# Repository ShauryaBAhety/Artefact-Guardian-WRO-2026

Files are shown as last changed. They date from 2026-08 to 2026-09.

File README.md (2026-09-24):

# Artefact Guardian 🤖

### A robotic arm that moves with hand gestures. Yes, we made a robot listen to our hands.

Artefact Guardian is our **WRO 2026 Future Innovators** project based on the theme **"Robots Meet Culture."**

The basic idea is pretty simple:

**Use computer vision to detect hand gestures → send commands to an ESP32 → move a robotic arm → handle artefacts without someone having to constantly touch them.**

We are still improving a lot of things, but this is where we've reached so far.

---

## So... what does it actually do?

The system uses a camera to look at your hand and detect its movement and gestures.

Those gestures are turned into commands, which are sent to an **ESP32**. The ESP32 then controls the servos on the arm.

Basically:

```text
Your hand
   ↓
Camera
   ↓
Hand tracking
   ↓
Gesture recognition
   ↓
ESP32
   ↓
Servos
   ↓
Robotic arm
   ↓
Artefact
```

We wanted the interaction to feel more natural than using a joystick or a bunch of buttons.

Also, waving at a robot is way cooler.

---

## Why did we make this?

Cultural artefacts can be extremely fragile and valuable. Moving them around manually isn't always ideal, especially when they need to be handled repeatedly.

Our idea was to build a system that can help with controlled handling while keeping direct human interaction to a minimum.

That's the idea at least.

Now we just have to make the robot actually cooperate.

---

## What are we using?

### Hardware

* **ESP32**
* **5 × DS3218 servo motors**
* **2 × 18650 batteries**
* **Buck converter**
* **Camera**
* Custom mechanical parts
* 3D-printed components

The five servos are used for the different movements of the arm, including the base, shoulder, elbow, wrist and gripper.

### Software

* **Python**
* **MediaPipe**
* Computer vision / hand tracking
* **ESP32 firmware**
* Servo control

### CAD

* **Fusion 360**
* 3D modelling
* Mechanical design and prototyping

---

## Gesture Control 🖐️

Our computer vision system detects the hand and uses the landmarks from it to figure out what we're doing.

Some of the gestures we've been using include:

```text
Open Palm  →  Activate / Control
Fist       →  Stop / Hold
Hand Motion → Arm movement
```

The exact control system is still being worked on and calibrated.

The robot does sometimes misunderstand us.

We're choosing to call that "AI behaviour."

---

## The arm

The arm has multiple degrees of movement controlled by the servo motors.

Current servo setup:

```text
Base
  ↓
Shoulder
  ↓
Elbow
  ↓
Wrist
  ↓
Gripper
```

The gripper is designed to pick up and move an object once the arm is positioned correctly.

Getting the arm to move is one thing.

Getting it to move **where we actually want it to move** is a completely different problem.

---

## Repository

Everything is being kept in this repo so the project doesn't become one giant folder called:

`FINAL_FINAL_REAL_ONE_USE_THIS`

Current structure:

```text
Artefact-Guardian-WRO-2026/
│
├── Artefact-Guardian-CAD/
│   └── CAD files and mechanical designs
│
├── Computer_vision/
│   └── Hand tracking and gesture recognition
│
├── Firmware/
│   └── ESP32/
│       └── Robot control code
│
├── Hardware/
│   └── Electronics and hardware information
│
├── documentation/
│   └── Notes, development and testing
│
└── .github/
```

---

## Development

This project has gone through a lot of trial and error.

We've tried different ideas for:

* Arm positioning
* IMU sensing
* Gesture recognition
* Servo control
* Mechanical design
* Computer vision
* Calibration

A fairly accurate representation of development has been:

```text
Build it
   ↓
Test it
   ↓
Something doesn't work
   ↓
Spend an unreasonable amount of time figuring out why
   ↓
Change three things
   ↓
It works
   ↓
Break something else
   ↓
Repeat
```

That's basically robotics.

---

## CAD & Mechanical Design

The mechanical parts of the robot are designed in Fusion 360 before being made.

This includes things like:

* Arm components
* Gripper
* Servo mounts
* Structural parts
* Different design iterations

Not every design made it to the final robot.

Some were good.

Some looked good until we actually tried to build them.

---

## Testing & Calibration

A large part of this project has been calibration.

We've been testing:

* Servo positions
* Joint limits
* Gripper movement
* Arm movement
* Gesture detection
* Power delivery
* Mechanical stability
* Repeatability

A robot can look perfectly aligned on a computer screen and then completely change its opinion once it exists in real life.

---

## Current Status

### ✅ Working

* ESP32 servo control
* Robotic arm movement
* Hand tracking
* Gesture-based control
* CAD development
* Basic hardware integration

### 🔧 Still working on

* Better gesture reliability
* More precise arm movement
* Calibration
* Object positioning
* Mechanical improvements
* Full system integration

There is still quite a bit left to improve.

---

## Future Ideas

Some things we'd like to add or improve:

* Better object detection
* Better wrist control
* More accurate positioning
* Collision detection
* Smoother movement
* Improved gripper design
* More reliable gesture recognition
* Better integration between the vision system and the arm
* Possibly using another camera for more accurate positioning

The goal is to get from:

> "Look, the robot moved."

to:

> "Look, it actually did exactly what we wanted."

---

## WRO 2026 🏆

**Competition:** World Robot Olympiad 2026 – Future Innovators
**Theme:** Robots Meet Culture
**Team:** JNS Future Minds
**School:** Jamnabai Narsee School, GIFT City, Gandhinagar

### Team

* **Shaurya Bahety**
* **Raj Singh**
* **Vivaan Vashistha**

---

## Photos / Videos

We'll keep adding photos, CAD renders and testing videos here as the project develops.

Because obviously you can't have a robotics project without showing the robot.

---

## Open Source

This project is open source, so you can look through the:

* Code
* CAD
* Hardware
* Documentation
* Experiments

Hopefully it is useful to someone else working on robotics, computer vision or just trying to make a robot do something vaguely useful.

Feedback and ideas are welcome.

---

## Built with

**ESP32 + Python + MediaPipe + Servo Motors + Fusion 360 + 3D Printing + a lot of debugging**

---

# Why Artefact Guardian?

We wanted to build something where robotics could actually interact with culture instead of just being another robot that follows a line around a track.

The idea is to use technology to make the handling of cultural artefacts more controlled and practical.

And also...

we really wanted to build a robotic arm.

So here we are.

---

## 🚀 That's Artefact Guardian

We're still building, testing and breaking things.

More updates coming as the robot gets better.

**Build → Test → Break → Fix → Repeat.**

That's pretty much the entire project.

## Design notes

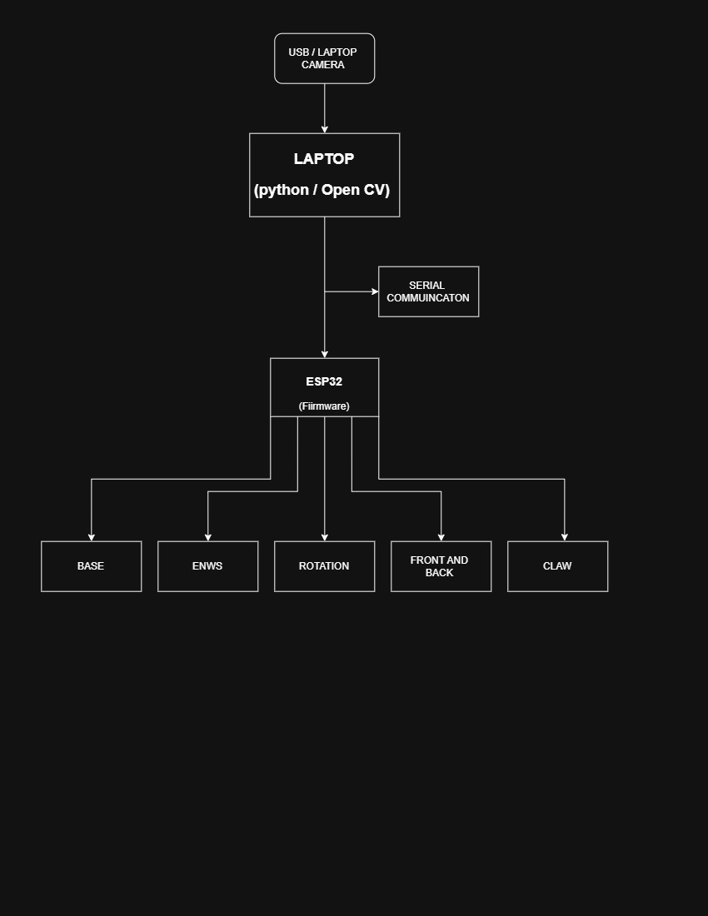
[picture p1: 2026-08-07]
Hardware/Circuit diagrams/System_Block_Diagram.jpg

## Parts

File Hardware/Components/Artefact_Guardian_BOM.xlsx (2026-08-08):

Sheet: BOM
ARTEFACT GUARDIAN – WRO 2026
Bill of Materials (BOM) – Final Robot & Spares
Product Name | Quantity | Unit Price (₹) | Total Price (₹) | Status
DS3218 high torque servo motors | 5 | ₹1582.00 | ₹7910.00 | Used
16 Channel PWM Servo Motor Driver I2C Module | 1 | ₹258.00 | ₹258.00 | Spare / Not used
Wire Stripper and Cutter | 1 | ₹60.00 | ₹60.00 | Used
2mm 1-meter Heat Shrink Polyolefin Sleeve Black | 3 | ₹12.71 | ₹38.13 | Used
High Quality 10 Core Rainbow Ribbon Flat Cable | 1 | ₹66.95 | ₹66.95 | Used
1 sq.mm Flexible Copper Wire 32/0.2 Black 13A | 3 | ₹24.58 | ₹73.74 | Used
1 sq.mm Flexible Copper Wire 32/0.2 Red 13A | 3 | ₹24.58 | ₹73.74 | Used
DC-DC Buck Converter Step-down Power Module 7-32V to 0.8-28V 12A 300W | 1 | ₹182.20 | ₹182.20 | Used
MURATA (SONY) US18650VTC6 3000mAh (7C) LI-ION BATTERY | 2 | ₹570.00 | ₹1140.00 | Used
MURATA (SONY) US18650VTC6 3000mAh (7C) LI-ION BATTERY | 1 | ₹570.00 | ₹570.00 | Spare
Black Plastic Storage Box Case Holder | 2 | ₹13.87 | ₹27.74 | Used
GRAND TOTAL |  |  | ₹10400.50
FINAL ROBOT SUBTOTAL |  |  | ₹9572.50
SPARES SUBTOTAL |  |  | ₹828.00
PURCHASE TOTAL |  |  | ₹10400.50
Notes
• 2 of the 3 purchased 18650 batteries are used in the final robot; 1 is spare.
• The 16-channel PWM servo driver is a spare and is NOT used in the final robot.
• Prices are based on the uploaded purchase BOM; totals are calculated automatically.
• The original purchase document lists GST-inclusive totals for several items.

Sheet: Final Robot Hardware
Component | Quantity | Purpose
ESP32 | 1 | Main controller
DS3218 servo motors | 5 | Base, shoulder, elbow, wrist and gripper
DC-DC buck converter | 1 | Power regulation
18650 Li-ion batteries | 2 | Final robot battery pack
Power switch | 1 | Main power control

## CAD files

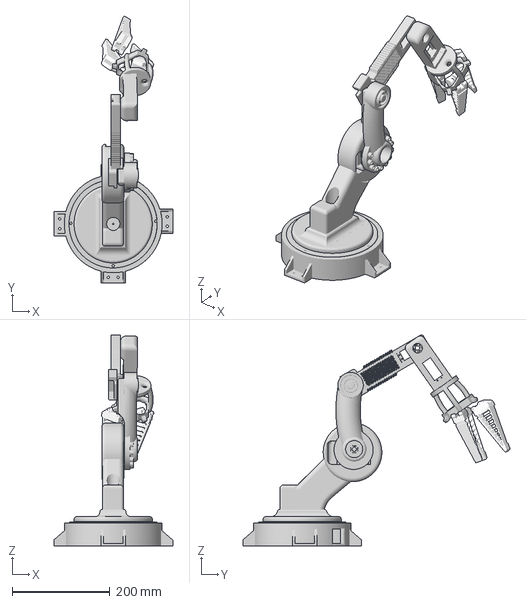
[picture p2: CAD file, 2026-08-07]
Artefact-Guardian-CAD/WRO_ASSEMBLY_FINAL.3mf
242.8 x 545.8 x 431.5 mm

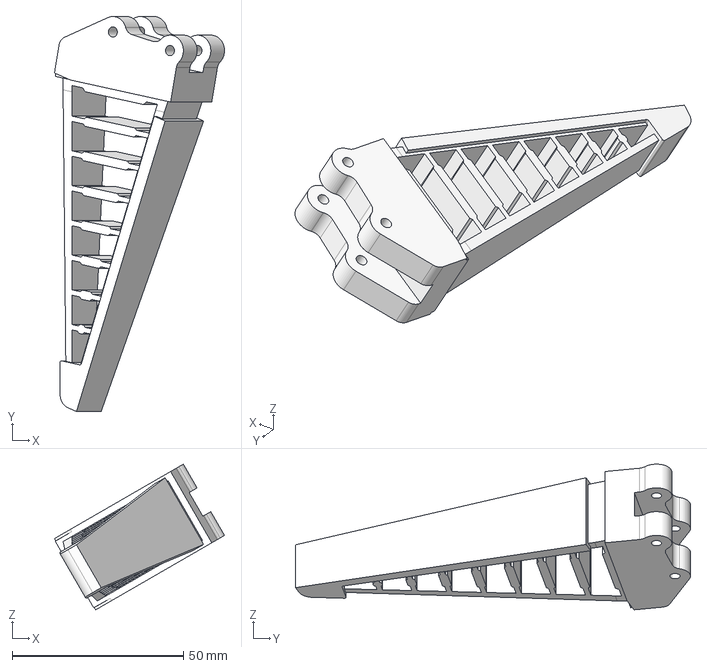
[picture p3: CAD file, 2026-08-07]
Artefact-Guardian-CAD/WRO_CLAW_FINAL.step
49.6 x 115.2 x 42.5 mm

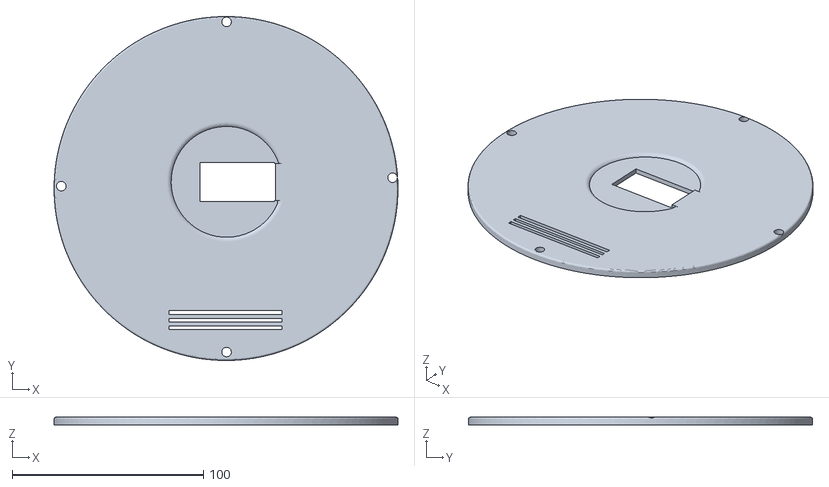
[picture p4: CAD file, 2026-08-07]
Artefact-Guardian-CAD/WRO_BASE_LID_FINAL.stl
180.0 x 180.0 x 4.00

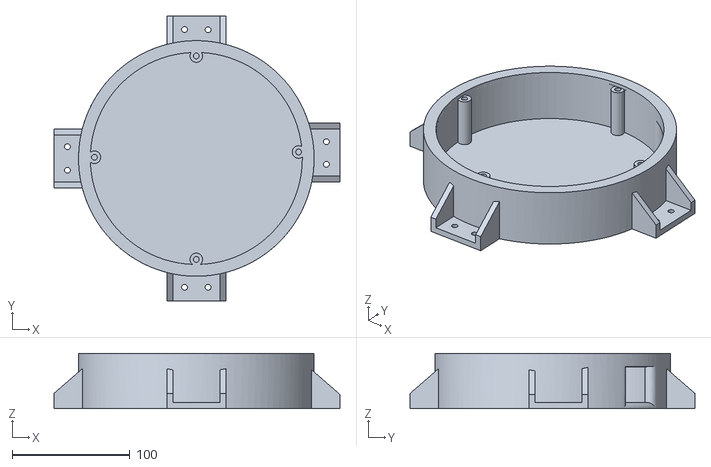
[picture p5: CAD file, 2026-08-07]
Artefact-Guardian-CAD/WRO_BASE_FINAL.stl
242.8 x 241.8 x 46.8

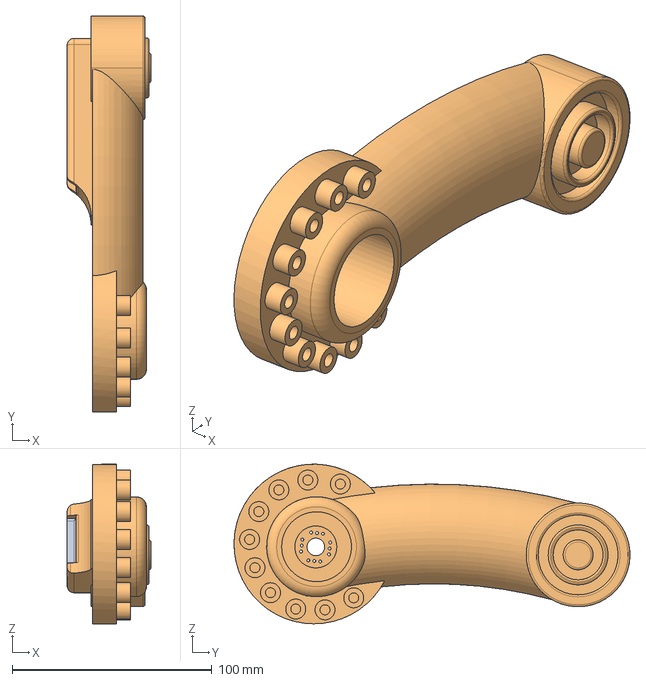
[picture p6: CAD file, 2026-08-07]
Artefact-Guardian-CAD/WRO_ROTATION_FINAL.step
42.0 x 198.4 x 80.0 mm

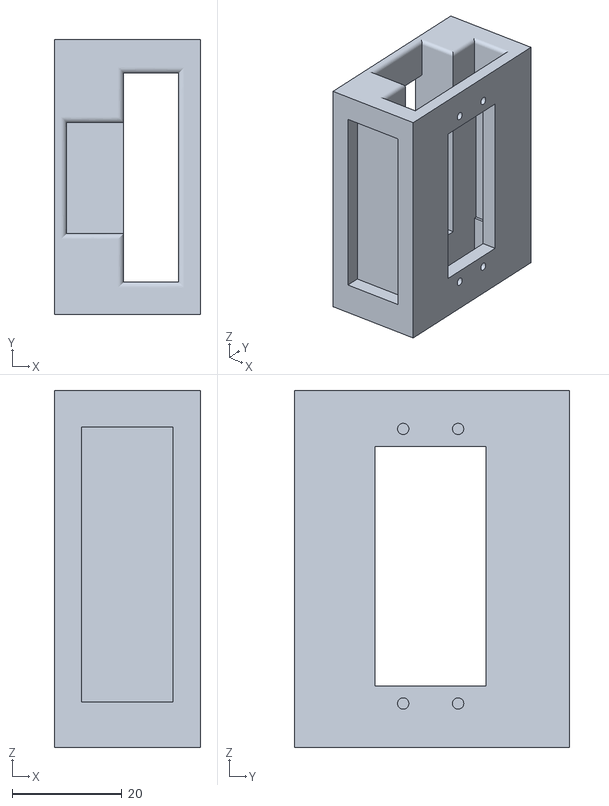
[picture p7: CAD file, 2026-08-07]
Artefact-Guardian-CAD/WRO_SLOT_FINAL.stl
26.6 x 50.0 x 65.0

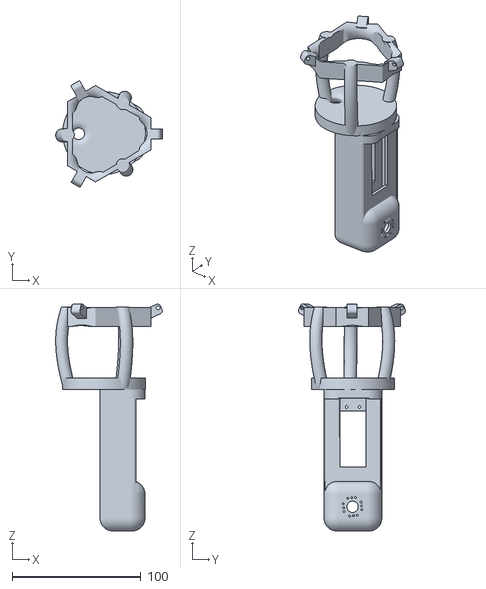
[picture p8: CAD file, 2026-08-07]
Artefact-Guardian-CAD/WRO_CLAW_CONNECTOR_FINAL.stl
83.0 x 83.2 x 176.6

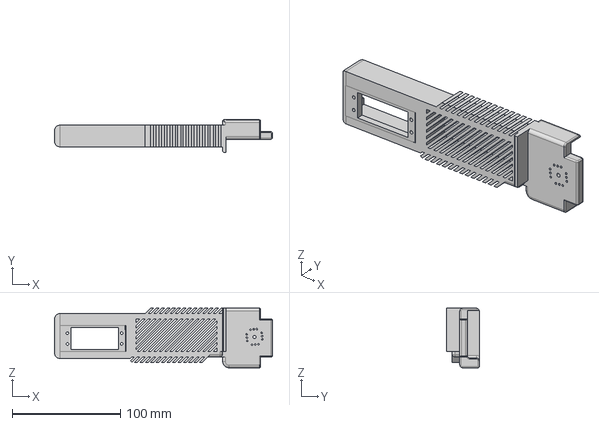
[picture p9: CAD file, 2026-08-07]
Artefact-Guardian-CAD/WRO_FRONT_BACK_FINAL.step
201.0 x 30.0 x 55.0 mm

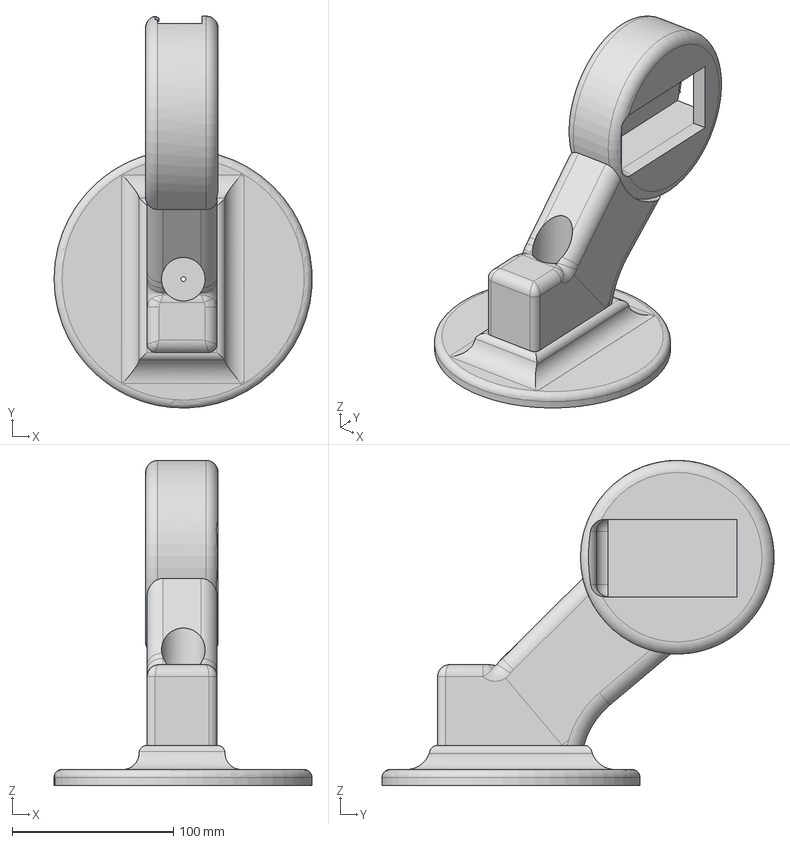
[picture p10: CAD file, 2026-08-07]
Artefact-Guardian-CAD/WRO_ENWS_FINAL.step
159.8 x 242.9 x 201.5 mm

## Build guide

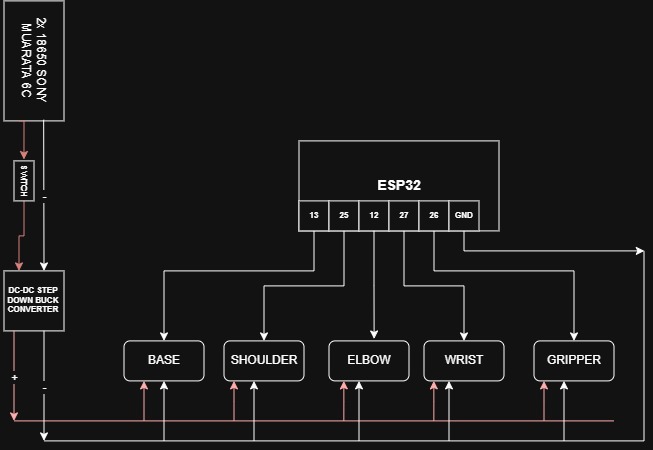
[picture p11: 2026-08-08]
Hardware/Wirings/Wiring diagram.jpg

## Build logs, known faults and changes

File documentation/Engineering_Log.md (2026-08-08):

# Engineering Log — Artefact Guardian

**Project Name:** Artefact Guardian  
**Competition:** WRO Future Innovators 2026  
**Team Members:** Shaurya Bahety, Raj, Vivaan  
**Repository:** Artefact-Guardian-WRO-2026  

---

## 1. Project Overview & What We're Building

* **The Problem:** Cultural heritage sites and museums handle priceless, fragile artefacts. Using bare hands risks transferring oils, dirt, or accidental drops, while big industrial arms are way too stiff and aggressive for delicate handling.
* **Our Solution:** **Artefact Guardian** — a gesture-controlled robotic hand and arm. It uses a camera for visual tracking, smooth motor feedback to stay steady, and calibrated finger movement for safe object handling.
* **Core Goal:** Mirror a human operator's hand movements in real-time so we can move delicate objects safely without ever touching them directly.

---

## 2. Step-by-Step Development Log

### Phase 1: Brainstorming & Architecture
* **Picking our input style:** We weighed up flex-glove sensors vs. Leap Motion vs. cameras. We went with camera-based computer vision (OpenCV + MediaPipe) so the operator doesn't need to wear bulky gloves or hardware.
* **Choosing microcontrollers:** Settled on an **ESP32** for the main logic because it's fast, dual-core, and handles UART communication smoothly. Paired it with an **Arduino UNO** to handle signal routing to the servos.

### Phase 2: CAD Design & 3D Printing Iterations
* **Base Assembly:**
  * *Iteration 1:* Designed the initial base housing, but realized the vertical clearance/height was too cramped to mount and align the top-to-bottom motor setup.
  * *Iteration 2:* Rescaled and extended the base housing to accommodate the vertical motor profile comfortably.
* **ENSW Rotation & Joint Module:**
  * Suffered several print failures due to strict servo slot tolerances.
  * Iterated dimension measurements multiple times until the DS3218 servo seated flush without stress on the 3D walls.
* **Front & Back Movement Joint:**
  * Went through 2–3 complete redesigns. Early mechanical designs struggled with weight distribution and didn't print cleanly.
  * *Material Switch:* Initial test prints in ABS failed or warped terribly. Switched away from ABS to PLA/TPU for better bed adhesion and structural consistency.
* **Claws & Grippers:**
  * *Print #1:* The initial claw design turned out far too small to grip actual sample museum artefacts safely.
  * *Print #2:* Upscaled the claw geometry and printed flexible TPU gripping surfaces.
* **Actuation Mechanism:**
  * Replaced slipping cables with an **inextensible nylon thread**. When the motor rotates, it winds/pulls the nylon thread to actuate the claw mechanisms with zero elastic stretch.

### Phase 3: Electronics & Power Management
* **Power Struggles:** Early on, powering the servos directly off the main microcontroller board kept tripping brownout resets on the ESP32 whenever the motors spiked.
* **Dual-Power Fix:** Split the wiring into two power rails — a heavy 5V/6V DC line specifically for the motor bus, and an isolated supply line for the ESP32 and MPU6050. Tied everything back to a shared ground.
* **Wiring Setup:** Neatened up our harness, generated our `Wiring diagram.jpg`, and put together the final component list in `BOM.xlsx`.

### Phase 4: Computer Vision & Gesture Control
* **Hand Tracking:** Built a Python pipeline with **OpenCV** and **MediaPipe Hands** to lock onto 21 key hand landmarks at smooth frame rates.
* **Math & Angles:** Wrote geometric functions that convert relative distance between hand landmarks into actual servo angles.
* **Talking over Serial:** Created a fast USB-Serial protocol to send target angles from Python directly to the ESP32 without lag or lost data packets.

### Phase 5: Calibration & Tuning
* **Servo Range Safety:** Charted upper and lower pulse-width limits for all DS3218 motors (in `Servo_Calibration.md`) to keep them from grinding gears or binding against 3D-printed stops.
* **Taming Sensor Noise:** Filtered out raw IMU noise from the MPU6050 so motor vibrations wouldn't mess up our orientation readings.

---

## 3. Roadblocks & How We Solved Them

| # | What Went Wrong | Why It Happened | How We Fixed It |
|---|---|---|---|
| **1** | Servo Jitter & ESP32 Resetting | High current draw from DS3218 motors pulled down voltage on the main board. | Isolated the motor power rail from logic, threw in decoupling capacitors, and double-checked common grounds. |
| **2** | Base Motor Clearance Issue | Original base CAD height was too short to fit the top-to-bottom motor setup. | Extended the base geometry vertically in Fusion 360 and reprinted. |
| **3** | Material Failures & Slot Misalignments | ABS warped heavily on mechanical prints, and ENSW servo slots were slightly off. | Ditched ABS due to print instability, tuned printer dimensions over multiple test runs, and printed grippers in flexible TPU. |
| **4** | Claw Sizing & Tendon Slipping | First claws were too small for artefacts, and elastic/smooth cables slipped. | Upscaled claw CAD design and adopted an inextensible nylon thread drive pulled directly by motor rotation. |
| **5** | Video Lag & Frame Drops | Processing high-res video frames slowed down hand tracking. | Scaled down camera resolution slightly and tweaked MediaPipe's confidence threshold settings. |

---

## 4. Team Roles & Who Built What

* **Shaurya Bahety:** Computer Vision scripts (Python/OpenCV/MediaPipe), ESP32 code, serial comms, and tying the hardware and software together.
* **Raj:** CAD modeling in Fusion 360, 3D printing tweaks, mechanical structure, and physical assembly.
* **Vivaan:** Power layout, wiring harness, hardware bench testing, and keeping track of components/BOM.

---

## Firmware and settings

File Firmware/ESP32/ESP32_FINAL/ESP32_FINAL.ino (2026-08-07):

/*
  5 DOF Servo Robotic Arm Firmware
  ESP32 Arduino Core
  Libraries: ESP32Servo, Preferences

  Servo Mapping:
    Base       -> GPIO13
    Shoulder   -> GPIO25
    Elbow      -> GPIO12
    Wrist      -> GPIO27
    Gripper    -> GPIO26

  Serial Commands:
    PING
    STOP
    ROTATE_TO:angle     (Base)
    SHOULDER_TO:angle   (Shoulder)
    ELBOW_TO:angle      (Elbow)
    TILT_TO:angle       (Wrist)
    GRIP:angle          (Gripper)
    WRIST_TO:angle      (ignored - robot has no dedicated wrist rotate servo)
    CALIBRATE
    SAVE
    HOME

  Calibration-mode-only commands:
    BASE+5 / BASE-5
    SHOULDER+5 / SHOULDER-5
    ELBOW+5 / ELBOW-5
    WRIST+5 / WRIST-5
    GRIP+2 / GRIP-2

  Motion: trapezoidal, acceleration-limited, velocity-based. No delay().
*/

#include <ESP32Servo.h>
#include <Preferences.h>

// ---------------------------------------------------------------------------
// Pin Mapping
// ---------------------------------------------------------------------------
#define PIN_BASE      13
#define PIN_SHOULDER  25
#define PIN_ELBOW     12
#define PIN_WRIST     27
#define PIN_GRIPPER   26

// ---------------------------------------------------------------------------
// Joint identifiers
// ---------------------------------------------------------------------------
enum JointId {
  JOINT_BASE = 0,
  JOINT_SHOULDER,
  JOINT_ELBOW,
  JOINT_WRIST,
  JOINT_GRIPPER,
  JOINT_COUNT
};

// ---------------------------------------------------------------------------
// Joint structure
// ---------------------------------------------------------------------------
struct Joint {
  Servo servo;
  int pin;

  float currentAngle;
  float targetAngle;
  float currentVelocity;   // deg/sec, signed

  float maxSpeed;          // deg/sec
  float acceleration;      // deg/sec^2

  float minAngle;
  float maxAngle;

  float homeAngle;

  const char* name;
};

Joint joints[JOINT_COUNT];

// ---------------------------------------------------------------------------
// Timing
// ---------------------------------------------------------------------------
unsigned long lastMotionUpdateMs = 0;
unsigned long lastHeartbeatMs = 0;
unsigned long lastCommandMs = 0;

const unsigned long MOTION_UPDATE_INTERVAL_MS = 20;   // 50 Hz motion loop
const unsigned long HEARTBEAT_INTERVAL_MS     = 1000; // 1 Hz heartbeat print
const unsigned long WATCHDOG_TIMEOUT_MS       = 5000; // no command -> stop

bool watchdogTripped = false;

// ---------------------------------------------------------------------------
// Mode
// ---------------------------------------------------------------------------
bool calibrationMode = false;
bool homingInProgress = false;

// ---------------------------------------------------------------------------
// Preferences (EEPROM-like storage)
// ---------------------------------------------------------------------------
Preferences prefs;
const char* PREFS_NAMESPACE = "robotarm";

// ---------------------------------------------------------------------------
// Serial input buffer
// ---------------------------------------------------------------------------
String serialBuffer = "";

// ---------------------------------------------------------------------------
// Forward declarations
// ---------------------------------------------------------------------------
void setupJoints();
void updateMotion();
void updateJoint(Joint &j, float dtSeconds);
void moveJoint(JointId id, float targetAngle);
void processCommand(String cmd);
void handleCalibrationCommand(String cmd);
void saveCalibration();
void loadCalibration();
void applyServoOutput();
void stopAllJoints();
void sendAck(const String &cmdEcho);
bool jointsAtHome();
bool jointAtTarget(Joint &j);
float clampf(float v, float lo, float hi);

// ---------------------------------------------------------------------------
// Setup
// ---------------------------------------------------------------------------
void setup() {
  Serial.begin(115200);
  while (!Serial) { /* wait for USB serial (non-blocking on most boards) */ }

  // Allow allocation of all timers for ESP32Servo
  ESP32PWM::allocateTimer(0);
  ESP32PWM::allocateTimer(1);
  ESP32PWM::allocateTimer(2);
  ESP32PWM::allocateTimer(3);

  setupJoints();

  prefs.begin(PREFS_NAMESPACE, false);
  loadCalibration();
  prefs.end();

  // On boot, assume physical servos are at their home position.
  for (int i = 0; i < JOINT_COUNT; i++) {
    joints[i].currentAngle  = joints[i].homeAngle;
    joints[i].targetAngle   = joints[i].homeAngle;
    joints[i].currentVelocity = 0.0f;
    joints[i].servo.write((int)joints[i].currentAngle);
  }

  lastMotionUpdateMs = millis();
  lastHeartbeatMs    = millis();
  lastCommandMs      = millis();

  Serial.println("READY");
}

// ---------------------------------------------------------------------------
// Main loop
// ---------------------------------------------------------------------------
void loop() {
  // ---- Serial read (non-blocking) ----
  while (Serial.available() > 0) {
    char c = (char)Serial.read();
    if (c == '\n' || c == '\r') {
      if (serialBuffer.length() > 0) {
        serialBuffer.trim();
        if (serialBuffer.length() > 0) {
          lastCommandMs = millis();
          watchdogTripped = false;
          if (calibrationMode) {
            handleCalibrationCommand(serialBuffer);
          } else {
            processCommand(serialBuffer);
          }
        }
        serialBuffer = "";
      }
    } else {
      serialBuffer += c;
      if (serialBuffer.length() > 64) {
        // Guard against runaway buffers
        serialBuffer = "";
      }
    }
  }

  // ---- Watchdog ----
  unsigned long now = millis();
  if (!watchdogTripped && (now - lastCommandMs > WATCHDOG_TIMEOUT_MS)) {
    watchdogTripped = true;
    stopAllJoints();
    Serial.println("WATCHDOG TIMEOUT");
  }

  // ---- Motion update (fixed-ish timestep) ----
  if (now - lastMotionUpdateMs >= MOTION_UPDATE_INTERVAL_MS) {
    float dt = (now - lastMotionUpdateMs) / 1000.0f;
    lastMotionUpdateMs = now;
    updateMotion();
    for (int i = 0; i < JOINT_COUNT; i++) {
      (void)dt;
    }
  }

  // ---- Homing completion check ----
  if (homingInProgress && jointsAtHome()) {
    homingInProgress = false;
    Serial.println("HOME COMPLETE");
  }

  // ---- Heartbeat ----
  if (now - lastHeartbeatMs >= HEARTBEAT_INTERVAL_MS) {
    lastHeartbeatMs = now;
    Serial.println("HEARTBEAT");
  }
}

// ---------------------------------------------------------------------------
// Joint setup: pins, limits, speed/acceleration profiles
// ---------------------------------------------------------------------------
void setupJoints() {
  joints[JOINT_BASE].pin          = PIN_BASE;
  joints[JOINT_BASE].name         = "BASE";
  joints[JOINT_BASE].minAngle     = 0.0f;
  joints[JOINT_BASE].maxAngle     = 180.0f;
  joints[JOINT_BASE].maxSpeed     = 60.0f;   // deg/sec
  joints[JOINT_BASE].acceleration = 90.0f;   // deg/sec^2
  joints[JOINT_BASE].homeAngle    = 90.0f;

  joints[JOINT_SHOULDER].pin          = PIN_SHOULDER;
  joints[JOINT_SHOULDER].name         = "SHOULDER";
  joints[JOINT_SHOULDER].minAngle     = 0.0f;
  joints[JOINT_SHOULDER].maxAngle     = 180.0f;
  joints[JOINT_SHOULDER].maxSpeed     = 50.0f;
  joints[JOINT_SHOULDER].acceleration = 70.0f;
  joints[JOINT_SHOULDER].homeAngle    = 90.0f;

  joints[JOINT_ELBOW].pin          = PIN_ELBOW;
  joints[JOINT_ELBOW].name         = "ELBOW";
  joints[JOINT_ELBOW].minAngle     = 0.0f;
  joints[JOINT_ELBOW].maxAngle     = 180.0f;
  joints[JOINT_ELBOW].maxSpeed     = 55.0f;
  joints[JOINT_ELBOW].acceleration = 80.0f;
  joints[JOINT_ELBOW].homeAngle    = 90.0f;

  joints[JOINT_WRIST].pin          = PIN_WRIST;
  joints[JOINT_WRIST].name         = "WRIST";
  joints[JOINT_WRIST].minAngle     = 0.0f;
  joints[JOINT_WRIST].maxAngle     = 180.0f;
  joints[JOINT_WRIST].maxSpeed     = 65.0f;
  joints[JOINT_WRIST].acceleration = 100.0f;
  joints[JOINT_WRIST].homeAngle    = 90.0f;

  // Gripper: ~4x slower than the other joints, protects grasped artefacts
  joints[JOINT_GRIPPER].pin          = PIN_GRIPPER;
  joints[JOINT_GRIPPER].name         = "GRIPPER";
  joints[JOINT_GRIPPER].minAngle     = 0.0f;
  joints[JOINT_GRIPPER].maxAngle     = 180.0f;
  joints[JOINT_GRIPPER].maxSpeed     = 15.0f;  // ~60/4
  joints[JOINT_GRIPPER].acceleration = 20.0f;  // ~80/4
  joints[JOINT_GRIPPER].homeAngle    = 90.0f;

  for (int i = 0; i < JOINT_COUNT; i++) {
    joints[i].currentAngle    = joints[i].homeAngle;
    joints[i].targetAngle     = joints[i].homeAngle;
    joints[i].currentVelocity = 0.0f;
    joints[i].servo.setPeriodHertz(50);
    joints[i].servo.attach(joints[i].pin, 500, 2400);
  }
}

// ---------------------------------------------------------------------------
// Motion: trapezoidal acceleration-limited update for every joint
// ---------------------------------------------------------------------------
void updateMotion() {
  static unsigned long lastUpdate = millis();
  unsigned long now = millis();
  float dt = (now - lastUpdate) / 1000.0f;
  lastUpdate = now;

  if (dt <= 0.0f) return;
  if (dt > 0.1f) dt = 0.1f; // clamp large gaps (e.g. after blocking serial reads)

  for (int i = 0; i < JOINT_COUNT; i++) {
    updateJoint(joints[i], dt);
  }

  applyServoOutput();
}

// Acceleration-limited, non-overshooting single-joint update.
void updateJoint(Joint &j, float dtSeconds) {
  float error = j.targetAngle - j.currentAngle;

  // Already essentially at target: snap and stop cleanly (no oscillation).
  if (fabs(error) < 0.05f && fabs(j.currentVelocity) < 0.5f) {
    j.currentAngle = j.targetAngle;
    j.currentVelocity = 0.0f;
    return;
  }

  float direction = (error >= 0.0f) ? 1.0f : -1.0f;
  float distanceToTarget = fabs(error);

  // Distance needed to decelerate from current speed to zero.
  float stoppingDistance = (j.currentVelocity * j.currentVelocity) /
                            (2.0f * j.acceleration);

  float desiredVelocity;

  if (distanceToTarget <= stoppingDistance) {
    // Decelerate toward zero so we land exactly on target, no overshoot.
    desiredVelocity = direction *
        sqrt(2.0f * j.acceleration * max(distanceToTarget, 0.0f));
  } else {
    // Accelerate (or cruise) toward max speed in the required direction.
    desiredVelocity = direction * j.maxSpeed;
  }

  // Apply acceleration limit when moving currentVelocity -> desiredVelocity.
  float velocityDelta = desiredVelocity - j.currentVelocity;
  float maxDeltaThisStep = j.acceleration * dtSeconds;
  velocityDelta = clampf(velocityDelta, -maxDeltaThisStep, maxDeltaThisStep);

  j.currentVelocity += velocityDelta;
  j.currentVelocity = clampf(j.currentVelocity, -j.maxSpeed, j.maxSpeed);

  // Integrate position.
  float step = j.currentVelocity * dtSeconds;

  // Never overshoot the target in a single step.
  if ((direction > 0 && step > distanceToTarget) ||
      (direction < 0 && -step > distanceToTarget)) {
    j.currentAngle = j.targetAngle;
    j.currentVelocity = 0.0f;
  } else {
    j.currentAngle += step;
  }

  j.currentAngle = clampf(j.currentAngle, j.minAngle, j.maxAngle);
}

void applyServoOutput() {
  for (int i = 0; i < JOINT_COUNT; i++) {
    int angleInt = (int)round(joints[i].currentAngle);
    angleInt = (int)clampf(angleInt, joints[i].minAngle, joints[i].maxAngle);
    joints[i].servo.write(angleInt);
  }
}

// ---------------------------------------------------------------------------
// Command a joint to move toward a new target (keeps current velocity,
// so continuous streams of targets glide instead of restarting motion).
// ---------------------------------------------------------------------------
void moveJoint(JointId id, float targetAngle) {
  Joint &j = joints[id];
  targetAngle = clampf(targetAngle, j.minAngle, j.maxAngle);
  j.targetAngle = targetAngle;
}

// ---------------------------------------------------------------------------
// Normal-mode command processing
// ---------------------------------------------------------------------------
void processCommand(String cmd) {
  cmd.trim();

  if (cmd.equalsIgnoreCase("PING")) {
    sendAck("PING");
    return;
  }

  if (cmd.equalsIgnoreCase("STOP")) {
    stopAllJoints();
    sendAck("STOP");
    return;
  }

  if (cmd.equalsIgnoreCase("CALIBRATE")) {
    calibrationMode = true;
    Serial.println("CALIBRATION MODE");
    return;
  }

  if (cmd.equalsIgnoreCase("SAVE")) {
    saveCalibration();
    Serial.println("SAVED");
    return;
  }

  if (cmd.equalsIgnoreCase("HOME")) {
    calibrationMode = false;
    homingInProgress = true;
    for (int i = 0; i < JOINT_COUNT; i++) {
      moveJoint((JointId)i, joints[i].homeAngle);
    }
    sendAck("HOME");
    return;
  }

  int sepIndex = cmd.indexOf(':');
  if (sepIndex < 0) {
    // Unrecognized command with no parameter — silently ignore.
    return;
  }

  String key = cmd.substring(0, sepIndex);
  String valueStr = cmd.substring(sepIndex + 1);
  valueStr.trim();
  float value = valueStr.toFloat();

  if (key.equalsIgnoreCase("ROTATE_TO")) {
    moveJoint(JOINT_BASE, value);
    sendAck("ROTATE_TO:" + valueStr);
  } else if (key.equalsIgnoreCase("SHOULDER_TO")) {
    moveJoint(JOINT_SHOULDER, value);
    sendAck("SHOULDER_TO:" + valueStr);
  } else if (key.equalsIgnoreCase("ELBOW_TO")) {
    moveJoint(JOINT_ELBOW, value);
    sendAck("ELBOW_TO:" + valueStr);
  } else if (key.equalsIgnoreCase("TILT_TO")) {
    moveJoint(JOINT_WRIST, value);
    sendAck("TILT_TO:" + valueStr);
  } else if (key.equalsIgnoreCase("GRIP")) {
    moveJoint(JOINT_GRIPPER, value);
    sendAck("GRIP:" + valueStr);
  } else if (key.equalsIgnoreCase("WRIST_TO")) {
    // Explicitly ignored: robot has no dedicated wrist-rotate servo.
    return;
  }
  // Any other unknown command is silently ignored.
}

// ---------------------------------------------------------------------------
// Calibration-mode command processing
// ---------------------------------------------------------------------------
void handleCalibrationCommand(String cmd) {
  cmd.trim();

  // Allow escaping calibration mode via the global commands too.
  if (cmd.equalsIgnoreCase("SAVE")) {
    saveCalibration();
    Serial.println("SAVED");
    return;
  }
  if (cmd.equalsIgnoreCase("HOME")) {
    calibrationMode = false;
    homingInProgress = true;
    for (int i = 0; i < JOINT_COUNT; i++) {
      moveJoint((JointId)i, joints[i].homeAngle);
    }
    sendAck("HOME");
    return;
  }
  if (cmd.equalsIgnoreCase("STOP")) {
    stopAllJoints();
    sendAck("STOP");
    return;
  }
  if (cmd.equalsIgnoreCase("PING")) {
    sendAck("PING");
    return;
  }

  struct CalMap {
    const char* token;
    JointId joint;
    float delta;
  };

  static const CalMap table[] = {
    { "BASE+5",      JOINT_BASE,     5.0f  },
    { "BASE-5",      JOINT_BASE,    -5.0f  },
    { "SHOULDER+5",  JOINT_SHOULDER, 5.0f  },
    { "SHOULDER-5",  JOINT_SHOULDER,-5.0f  },
    { "ELBOW+5",     JOINT_ELBOW,    5.0f  },
    { "ELBOW-5",     JOINT_ELBOW,   -5.0f  },
    { "WRIST+5",     JOINT_WRIST,    5.0f  },
    { "WRIST-5",     JOINT_WRIST,   -5.0f  },
    { "GRIP+2",      JOINT_GRIPPER,  2.0f  },
    { "GRIP-2",      JOINT_GRIPPER, -2.0f  },
  };

  for (unsigned int i = 0; i < sizeof(table) / sizeof(table[0]); i++) {
    if (cmd.equalsIgnoreCase(table[i].token)) {
      Joint &j = joints[table[i].joint];
      float newTarget = j.targetAngle + table[i].delta;
      moveJoint(table[i].joint, newTarget);
      sendAck(String(table[i].token));
      return;
    }
  }

  // Unrecognized calibration command — ignored.
}

// ---------------------------------------------------------------------------
// Preferences: save / load calibration (home positions)
// ---------------------------------------------------------------------------
void saveCalibration() {
  prefs.begin(PREFS_NAMESPACE, false);
  prefs.putFloat("baseHome",     joints[JOINT_BASE].targetAngle);
  prefs.putFloat("shoulderHome", joints[JOINT_SHOULDER].targetAngle);
  prefs.putFloat("elbowHome",    joints[JOINT_ELBOW].targetAngle);
  prefs.putFloat("wristHome",    joints[JOINT_WRIST].targetAngle);
  prefs.putFloat("gripperHome",  joints[JOINT_GRIPPER].targetAngle);
  prefs.end();

  joints[JOINT_BASE].homeAngle     = joints[JOINT_BASE].targetAngle;
  joints[JOINT_SHOULDER].homeAngle = joints[JOINT_SHOULDER].targetAngle;
  joints[JOINT_ELBOW].homeAngle    = joints[JOINT_ELBOW].targetAngle;
  joints[JOINT_WRIST].homeAngle    = joints[JOINT_WRIST].targetAngle;
  joints[JOINT_GRIPPER].homeAngle  = joints[JOINT_GRIPPER].targetAngle;
}

void loadCalibration() {
  joints[JOINT_BASE].homeAngle =
      prefs.getFloat("baseHome", joints[JOINT_BASE].homeAngle);
  joints[JOINT_SHOULDER].homeAngle =
      prefs.getFloat("shoulderHome", joints[JOINT_SHOULDER].homeAngle);
  joints[JOINT_ELBOW].homeAngle =
      prefs.getFloat("elbowHome", joints[JOINT_ELBOW].homeAngle);
  joints[JOINT_WRIST].homeAngle =
      prefs.getFloat("wristHome", joints[JOINT_WRIST].homeAngle);
  joints[JOINT_GRIPPER].homeAngle =
      prefs.getFloat("gripperHome", joints[JOINT_GRIPPER].homeAngle);
}

// ---------------------------------------------------------------------------
// Stop: freeze every joint exactly where it is right now.
// ---------------------------------------------------------------------------
void stopAllJoints() {
  for (int i = 0; i < JOINT_COUNT; i++) {
    joints[i].targetAngle = joints[i].currentAngle;
    joints[i].currentVelocity = 0.0f;
  }
}

// ---------------------------------------------------------------------------
// Helpers
// ---------------------------------------------------------------------------
void sendAck(const String &cmdEcho) {
  Serial.print("ACK:");
  Serial.println(cmdEcho);
}

bool jointAtTarget(Joint &j) {
  return fabs(j.targetAngle - j.currentAngle) < 0.1f &&
         fabs(j.currentVelocity) < 0.1f;
}

bool jointsAtHome() {
  for (int i = 0; i < JOINT_COUNT; i++) {
    if (fabs(joints[i].currentAngle - joints[i].homeAngle) > 0.5f) {
      return false;
    }
  }
  return true;
}

float clampf(float v, float lo, float hi) {
  if (v < lo) return lo;
  if (v > hi) return hi;
  return v;
}

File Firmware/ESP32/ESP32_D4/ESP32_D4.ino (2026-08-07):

/*
  Artefact Guardian - ESP32 direct-servo firmware (single-file build)
  Protocol:
    PING
    STOP
    ESTOP
    HOME
    ROTATE_TO:<0-180>
    SHOULDER_TO:<0-180>
    ELBOW_TO:<0-180>
    TILT_TO:<0-180>
    WRIST_TO:<0-180>
    GRIP:<0-180>
    MOVE:a,b,c,d,e,f
  Status: STATUS:UNHOMED|HOMING|READY|MOVING|IDLE|STOPPED|WATCHDOG|ERROR
  DONE is sent once, edge-triggered, when the arm settles at its target.
*/

#include <ESP32Servo.h>
#include <Preferences.h>
#include <ctype.h>
#include <math.h>
#include <string.h>
#include <stdlib.h>

// ============================================================
// CONFIG
// ============================================================
constexpr uint32_t BAUD_RATE      = 115200;
constexpr size_t   RX_BUFFER_SIZE = 96;

constexpr uint32_t CONTROL_PERIOD_MS    = 15;
constexpr uint32_t HEARTBEAT_TIMEOUT_MS = 3000;

constexpr size_t JOINT_COUNT = 6;

// GPIO12 is an ESP32 boot-strapping pin. SHOULDER moved off it -> GPIO14.
const int SERVO_PINS[JOINT_COUNT] = {13, 14, 25, 26, 27, 32};

// Mechanical limits - tune for YOUR physical arm before fitting an artefact.
const int MIN_ANGLE[JOINT_COUNT] = {15, 20, 20, 20, 20, 30};
const int MAX_ANGLE[JOINT_COUNT] = {165, 160, 160, 160, 160, 150};
const int SAFE_HOME[JOINT_COUNT] = {90, 90, 90, 90, 90, 30};

// Per-joint glide factor: fraction of remaining error closed per cycle.
const float GLIDE_FACTOR[JOINT_COUNT] =
    {0.06f, 0.04f, 0.045f, 0.06f, 0.07f, 0.10f};

// Slower, conservative glide used only while homing from a possibly
// stale/estimated pose.
constexpr float HOMING_GLIDE_FACTOR = 0.02f;

// Below this error (deg) we snap to target instead of creeping forever -
// eliminates near-target servo buzzing/hunting.
constexpr float ANGLE_DEADBAND_DEG = 0.6f;

// Max angular change allowed per control cycle, in degrees.
constexpr float MAX_STEP_DEG_PER_CYCLE = 4.0f;

constexpr int SERVO_MIN_US = 500;
constexpr int SERVO_MAX_US = 2500;
constexpr int SERVO_PWM_HZ = 50;

constexpr char NVS_NAMESPACE[]  = "artefact_arm";
constexpr char NVS_KEY_PREFIX[] = "j"; // keys: j0..j5

// ============================================================
// TYPES
// ============================================================
enum Joint : uint8_t {
  BASE = 0,
  SHOULDER,
  ELBOW,
  WRIST_TILT,
  WRIST_ROTATE,
  GRIPPER,
};

enum class StopCause : uint8_t {
  NONE,
  USER,       // STOP command
  HEARTBEAT,  // no PING/command within HEARTBEAT_TIMEOUT_MS
  EMERGENCY,  // ESTOP command
};

enum class SystemState : uint8_t {
  UNHOMED,   // powered up, servos NOT attached, awaiting HOME command
  HOMING,    // gliding from last-known/estimated pose to SAFE_HOME
  READY,
  MOVING,
  IDLE,
  STOPPED,
  WATCHDOG,
};

// ============================================================
// PERSISTENCE (NVS) - last-known-settled angles survive reboot
// ============================================================
namespace persistence {

Preferences prefs;

void keyFor(size_t joint, char* out, size_t outSize) {
  snprintf(out, outSize, "%s%u", NVS_KEY_PREFIX, static_cast<unsigned>(joint));
}

// Returns false if nothing has ever been saved (first-ever boot / erased
// flash) - caller must not treat outAngles as meaningful in that case.
bool loadAngles(float outAngles[JOINT_COUNT]) {
  prefs.begin(NVS_NAMESPACE, /*readOnly=*/true);
  bool haveAll = true;
  char key[8];
  for (size_t j = 0; j < JOINT_COUNT; ++j) {
    keyFor(j, key, sizeof(key));
    if (!prefs.isKey(key)) {
      haveAll = false;
      break;
    }
    outAngles[j] = prefs.getFloat(key, NAN);
  }
  prefs.end();
  return haveAll;
}

// Call sparingly (on DONE / clean STOP) - not every control cycle - to
// limit flash wear.
void saveAngles(const float angles[JOINT_COUNT]) {
  prefs.begin(NVS_NAMESPACE, /*readOnly=*/false);
  char key[8];
  for (size_t j = 0; j < JOINT_COUNT; ++j) {
    keyFor(j, key, sizeof(key));
    prefs.putFloat(key, angles[j]);
  }
  prefs.end();
}

} // namespace persistence

// ============================================================
// SERVO CONTROL (hardware layer)
// ============================================================
namespace servo_control {

Servo servoBase, servoShoulder, servoElbow, servoWristTilt, servoWristRotate, servoGripper;
Servo* servos[JOINT_COUNT] = {
  &servoBase, &servoShoulder, &servoElbow,
  &servoWristTilt, &servoWristRotate, &servoGripper,
};
bool attached = false;

// Clamps a requested angle to this joint's mechanical limits.
// Returns -1 if the input is not finite (NaN/Inf) - "reject".
int clamp(Joint joint, float requestedAngle) {
  if (!isfinite(requestedAngle)) {
    return -1;
  }
  int rounded = static_cast<int>(lroundf(requestedAngle));
  if (rounded < MIN_ANGLE[joint]) rounded = MIN_ANGLE[joint];
  if (rounded > MAX_ANGLE[joint]) rounded = MAX_ANGLE[joint];
  return rounded;
}

// Configures PWM timers only. Does NOT attach or drive any servo, so no
// GPIO carries a PWM signal until attach() is explicitly called.
void init() {
  ESP32PWM::allocateTimer(0);
  ESP32PWM::allocateTimer(1);
  ESP32PWM::allocateTimer(2);
  ESP32PWM::allocateTimer(3);
}

// Attaches all servos and writes initialAngle[] as the very first pulse.
// Call this ONLY once the host has sent HOME - never automatically at boot -
// since there is no position feedback and an unconditional write here would
// be an uncommanded physical motion.
void attachAll(const float initialAngle[JOINT_COUNT]) {
  for (size_t j = 0; j < JOINT_COUNT; ++j) {
    servos[j]->setPeriodHertz(SERVO_PWM_HZ);
    servos[j]->attach(SERVO_PINS[j], SERVO_MIN_US, SERVO_MAX_US);
    servos[j]->write(static_cast<int>(lroundf(initialAngle[j])));
  }
  attached = true;
}

bool isAttached() { return attached; }

void writeAll(const float currentAngle[JOINT_COUNT]) {
  for (size_t j = 0; j < JOINT_COUNT; ++j) {
    servos[j]->write(static_cast<int>(lroundf(currentAngle[j])));
  }
}

} // namespace servo_control

// ============================================================
// MOTION CONTROL (interpolation / target tracking)
// ============================================================
namespace motion_control {

float targetAngle[JOINT_COUNT];
float currentAngle[JOINT_COUNT];
bool  useHomingGlide = false; // slower, more conservative glide while homing

void seedCurrentAngles(const float seedAngles[JOINT_COUNT]) {
  for (size_t j = 0; j < JOINT_COUNT; ++j) {
    currentAngle[j] = seedAngles[j];
  }
}

void setTarget(Joint joint, float clampedAngle) {
  targetAngle[joint] = clampedAngle;
}

void setAllTargets(const float clampedAngles[JOINT_COUNT]) {
  for (size_t j = 0; j < JOINT_COUNT; ++j) {
    targetAngle[j] = clampedAngles[j];
  }
}

// Freezes motion by making every joint's target equal to its current
// position, so nothing moves until a fresh command sets a new target.
void freezeInPlace() {
  for (size_t j = 0; j < JOINT_COUNT; ++j) {
    targetAngle[j] = currentAngle[j];
  }
}
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

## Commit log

2026-08-07 CAD files
    artefact guardian cad files :
    20% infill density-PLA (All parts except the claws
    [WRO_ASSEMBLY_FINAL.3mf, WRO_BASE_FINAL.stl, WRO_BASE_LID_FINAL.stl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]
2026-08-08 Wiring diagram
    recommended wiring diagram
2026-08-08 BOM and Components
    description of all components used for the robor
    [Artefact_Guardian_BOM.xlsx]
2026-09-24 Add project overview and details for Artefact Guardian
    Added detailed project description for Artefact Guardian, including functionality, hardware and software used, gesture control, current status, future ideas, and team information.
